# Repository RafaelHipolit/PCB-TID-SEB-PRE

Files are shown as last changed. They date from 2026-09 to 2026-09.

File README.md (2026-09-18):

# Projeto de PCB da IC: Instrumentação para o Estudo de Efeitos de Radiação em Dispositivos Eletrônicos

## Resumo da IC
O avanço da microeletrônica e a constante aplicação de dispositivos semicondutores em ambientes críticos, como os cenários aeroespaciais e nucleares, têm intensificado a necessidade de qualificar componentes eletrônicos quanto à sua tolerância à radiação ionizante. Nesse contexto, a caracterização precisa dos danos provocados exige instrumentação científica capaz de avaliar tanto os efeitos acumulativos, resultantes da Dose Ionizante Total (TID), quanto as falhas estocásticas provocadas por Efeitos de Evento Único (SEE). O presente trabalho teve como objetivo projetar e desenvolver uma plataforma eletrônica integrada, no formato de Placa de Circuito Impresso (PCB), dedicada ao estudo e à caracterização dos efeitos de radiação ionizante em transistores MOSFET de potência. 
        
O circuito implementado foi estruturado em três blocos funcionais distintos: um circuito para monitoramento de TID conectado à plataforma PXI, um circuito protetivo contra Efeitos de Queima por Sobrecorrente (SEB) baseado na Técnica de Limitação de Corrente e um circuito auxiliar de pré-amplificação focado na Espectroscopia de Carga.  Para viabilizar o uso dinâmico da plataforma sem a necessidade de reconfigurações manuais, a alternância de conexão entre os blocos operacionais e o Dispositivo Sob Teste (DUT) foi estabelecida por meio do chaveamento de relés de potência. O projeto elétrico, o layout das camadas e o modelo 3D da PCB foram desenvolvidos e validados computacionalmente no software KiCad, confirmando que a topologia concebida cumpre os requisitos de instrumentação.

---

# Metodologia

As técnicas de medição de efeitos de radiação em transistores, como a
Técnica de Limitação de Corrente e Técnica de Espectroscopia de Carga,
necessitam de componentes e equipamentos que existem comercialmente e
são comumente encontradas em laboratórios de física nuclear. Entretanto,
devido à grande variedade de dispositivos eletrônicos necessários para
implementar as diferentes técnicas, não existe uma solução comercial
viável de propósito geral para qualificação de transistores sob efeitos
de radiação. Assim, percebe-se uma necessidade de desenvolver uma
plataforma integrada de testes suficientemente geral que atenda
simultaneamente às exigências específicas de ensaios de efeitos
estocásticos e acumulativos de radiação para uma ampla gama de
transistores.

Tendo esse contexto em mente, este projeto de pesquisa visa projetar uma
plataforma integrada, na forma de placa de circuito impresso (PCB -
*Printed Circuit Board*) que auxilie o estudo e caracterização dos
efeitos de radiação ionizante em dispositivos eletrônicos. A PCB a ser
elaborada deve focar em TID para efeitos acumulativos e SEE para efeitos
estocásticos. Para medição de SEE deve-se utilizar a Técnica de
Limitação de Corrente e Técnica de Espectroscopia de Carga.

O circuito projetado na PCB deve ser dividido em três blocos: Circuito
TID, Circuito SEB e Circuito Pré-Amplificador. Os três circuitos devem
ser integrados de forma que apenas um esteja conectado ao DUT por vez e
que a troca do circuito conectado ao DUT possa ser realizada
dinamicamente.

## Circuito TID

Esse circuito deve auxiliar na medição do efeito de TID. Para isso ele
deve conectar os terminais do DUT a uma SMU para monitoramento de
parâmetros do dispositivo. No caso desse projeto, a SMU será por meio da
plataforma modular PXI (*PCI eXtensions for Instrumentation*). Portanto,
a saída deste circuito deve obedecer a padronização de conexão com a
plataforma PXI. Tal padrão consiste de nove eletrodos de controle e
automação, que obedece o seguinte ordenamento sequencial:

-   Eletrodo positivo de porta (POS G).

-   Eletrodo negativo de porta (NEG G).

-   Eletrodo positivo de dreno (POS D).

-   Eletrodo negativo de dreno (NED G).

-   Eletrodo negativo de sensoriamento de dreno (NEG SD).

-   Eletrodo positivo de sensoriamento de dreno (POS SD).

-   Fonte DC (+5 V).

-   Fonte DC (+5 V).

-   Fonte DC (+5 V).

Em nosso contexto, os últimos três terminais de fonte DC +5 V são
utilizados para controle automatizado de relês de alta tensão.

## Circuito SEB

O Circuito SEB deve auxiliar a medição do Efeito Único de Queima por
Sobrecorrente. Para isso, ele deve implementar a Técnica de Limitação de
Corrente com um arranjo de resistores de proteção. A saída do circuito
deve disponibiliza os sinais transientes do DUT para instrumentos
externos de aquisição. O terminal de saída desse circuito deve possuir
impedância de 50para evitar reflexões em sistemas de aquisição
ultra-rápidos. Além disso, o sistema protetivo deve possibilitar a
seleção do resistor de proteção apropriado (10 k- 1 M) ao DUT, de forma
a assegurar a eficácia da técnica de limitação de corrente.

## Circuito Pré-Amplificador

O Circuito Pré-Amplificador deve auxiliar o arranjo da Técnica de
Espectroscopia de Carga por meio da implementação do Pré-Amplificador
Sensível à Carga presente nesta técnica. Sua saída deve apresentar
impedância de 50 ohms para casamento com sistemas de aquisição
ultra-rápidos. Para definir o ganho nominal de pré-amplificação de
aproximadamente 45 mV/MeV em sensores de silício, um capacitor de
retroalimentação de 1 pF foi escolhido. Para possibilitar a
discriminação de eventos distintos induzidos por partículas ionizantes a
taxas médias inferiores a $2 \times 10^{6}$ eventos/s, tipicamente
adotadas em testes dedicados com aceleradores de partículas, um resistor
de retroalimentação de 100 kfoi considerado.

## Integração dos circuitos

Os três circuitos devem ser integrados de forma que apenas um esteja
conectado ao DUT por vez. Para realizar essa alternância de conexão deve
ser utilizados relés de potência para conectar apenas um dos circuitos
por vez ao DUT. O controle desses relés deve ser por meio plataforma
PXI, utilizando a conexão implementada no Circuito TID.

## Conexão com o transistor DUT

Visando o propósito generalista da plataforma integrada de testes e
buscando maior praticidade na substituição de diferentes DUTs na
instrumentação proposta, optou-se por realizar a conexão entre o DUT e o
sistema por meio do acoplamento entre uma PCB-mãe (sistema) e uma
PCB-filha (DUT), através de barras de pinos torneados. A PCB-filha deve
passar os sinais de porta, dreno e fonte. O uso dessa arquitetura
modular justifica-se por sua disponibilidade prévia no Laboratório onde
este projeto é realizado, facilitando o uso de diferentes transistores
na PCB elaborada neste projeto.

# Resultados

Este capítulo descreve o projeto de PCB elaborada para atender ao
objetivos do presente trabalho.

## Esquemático da PCB

A Figura mostra o esquemático da PCB
elaborada no software KiCad.

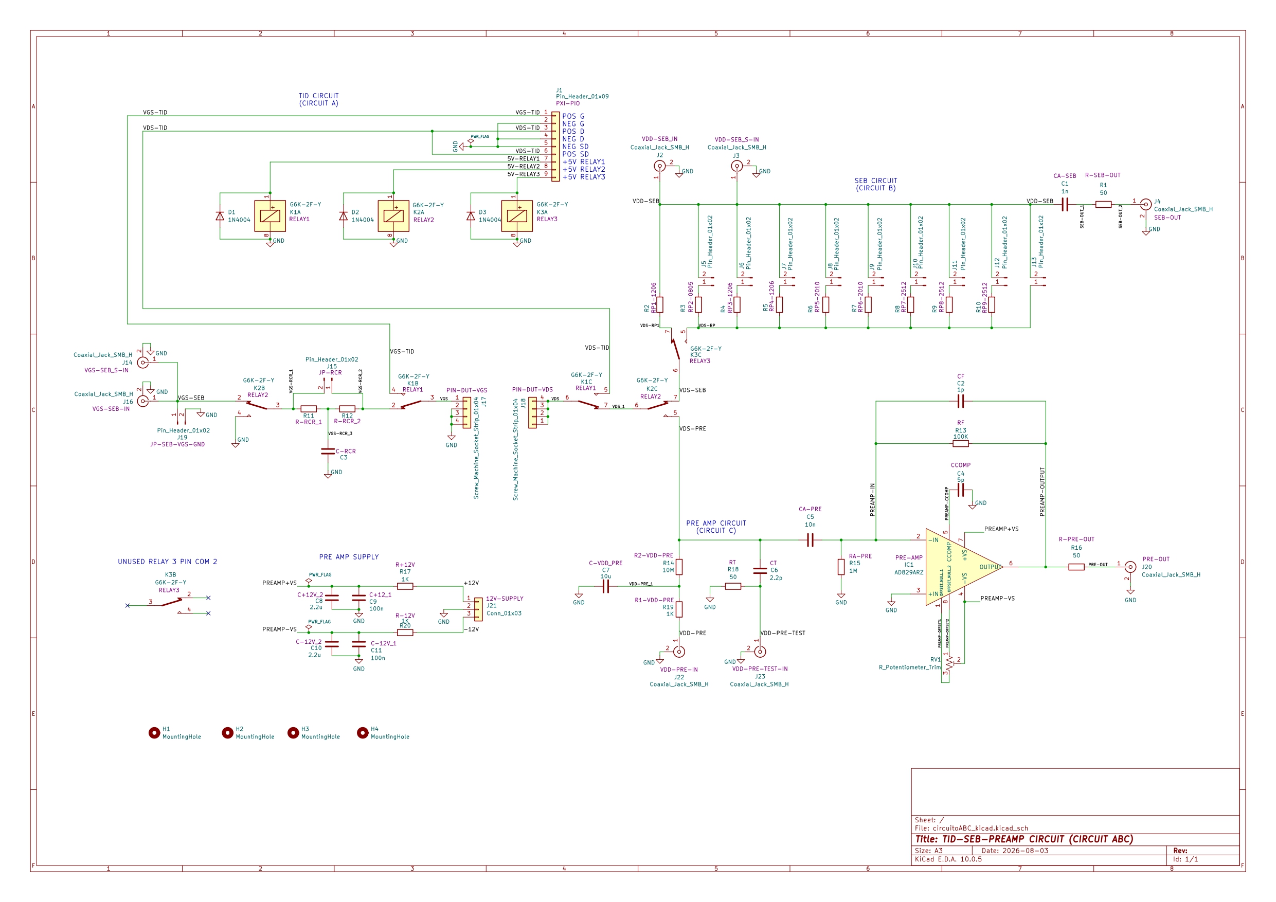
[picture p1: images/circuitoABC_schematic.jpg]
Esquemático da PCB.


Esquemático da PCB.

Esquemático da
PCB.

### Configuração da interface PXI

Os 9 pinos que se conectam à interface PXI seguem a estrutura na PCB:

-   POS G: sinal de tensão do *gate-source* do transistor.

-   NEG G: sinal de terra.

-   POS D: sinal de tensão do *drain-source* do transistor.

-   NEG D: sinal de terra.

-   NEG SD: sinal de terra.

-   POS SD: sinal de tensão do *drain-source* do transistor.

-   +5V RELAY1: ativa o relé 1 com 5V.

-   +5V RELAY2: ativa o relé 2 com 5V.

-   +5V RELAY3: ativa o relé 3 com 5V.

### Arranjo de resistores de proteção

No circuito SEB, devido a diferentes possíveis necessidades de valor
para o resistor de proteção empregado na Técnica de Limitação de
Corrente, foi elaborado um arranjo de resistores de proteção. Neste
arranjo há espaço para 9 resistores de proteção.

A conexão do resistor RP1 ou dos demais resistores pode ser alterada
dinamicamente utilizando o relé 3. Os resistores RP2 até RP9 estão
conectados em paralelo, porém cada um pode ser desconectado manualmente
utilizando um jumper. Ademais, uma trilha para conexão sem resistor de
proteção está presente.

### Configuração dos relés

Foram utilizados 3 relés duplos, ou seja, 3 circuitos integrados nos
quais cada um contém 2 relés que são ativados simultaneamente. Os relés
1 e 2 realizam a troca de conexão dos circuitos com o DUT. O relé 3
realiza a troca de resistor de proteção dinamicamente. A tabela descreve
a configuração de cada relé.

| -------- |--------------------- |---------------------------------| 
| --- |--- |---|
| Relé 1 |Normalmente Aberto |Conecta o porta e dreno do DUT ao Circuito TID| 
| |Normalmente Fechado |Conecta o porta e dreno do DUT ao Circuito SEB ou Pré-Amp.|
| -------- |--------------------- |--------------------------------|
| Relé 2 |Normalmente Aberto |Conecta o porta e dreno do DUT ao Circuito Pré-Amplificador | 
| |Normalmente Fechado |Conecta o porta e dreno do DUT ao Circuito SEB|
| -------- |--------------------- |--------------------------------|
| Relé 3 |Normalmente Aberto |Utiliza o resistores RP2 a RP9 como resistor de proteção | 
| |Normalmente Fechado |Utiliza o resistor RP1 como resistor de proteção|
| -------- |--------------------- |--------------------------------|

Configuração de cada relé.

## Layout da PCB

A Figura mostra o layout da PCB elaborada no
software KiCad. Na esquerda da PCB se encontra o Circuito SEB e Circuito
TID. Na borda da placa, encontram-se os conectores dos sinais de entrada
e saída do Circuito SEB. Em seguida é visível o arranjo de resistores de
proteção, os 3 relés e os pinos para conexão do Circuito TID com a
plataforma PXI. No centro da PCB encontram-se os pinos para conexão com
a PCB-filha e, portanto, conexão com o DUT. Na direita da PCB há o
Circuito Pré-Amplificador.

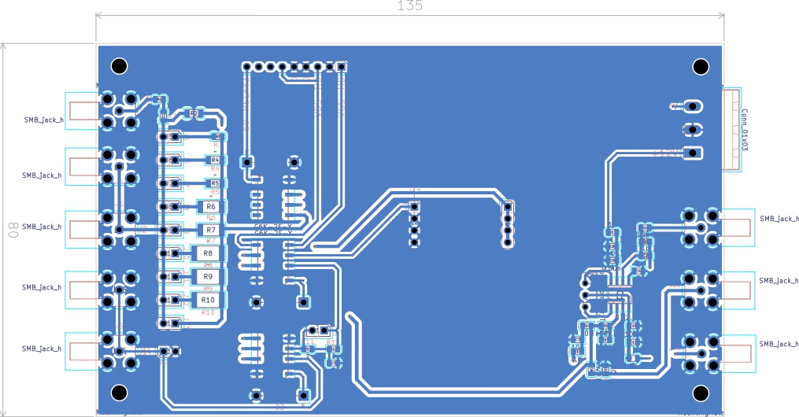
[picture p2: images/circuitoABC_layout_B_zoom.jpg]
Layout da camada inferior da PCB.


Layout da camada inferior da PCB.

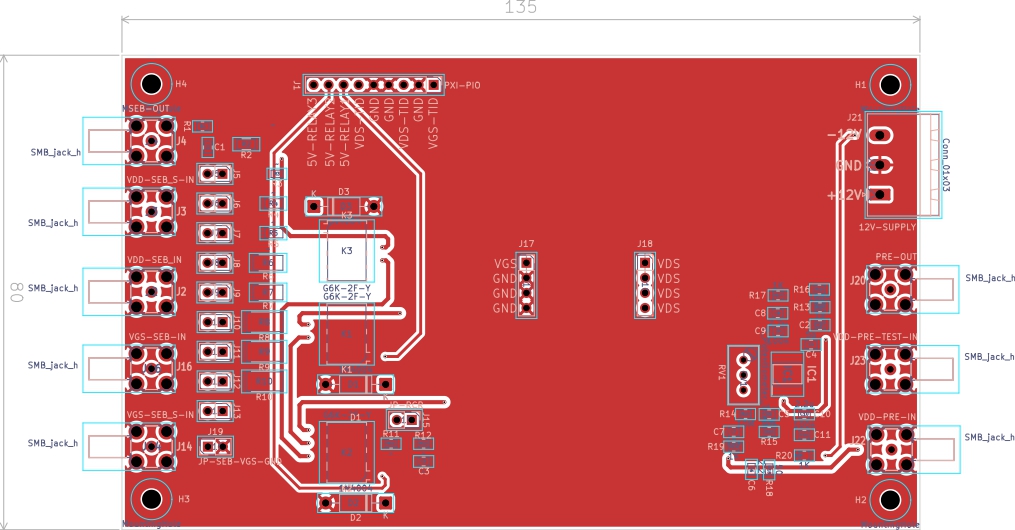
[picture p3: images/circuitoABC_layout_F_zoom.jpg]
Layout da camada superior da PCB


Layout da camada superior da PCB

A Figura mostra o modelo 3D da PCB no software
KiCad, no qual é possível visualizar todos os componentes da placa e as
legendas impressas na camada de serigrafia (*silkscreen*) dos conectores
de entrada e saída dos sinais.

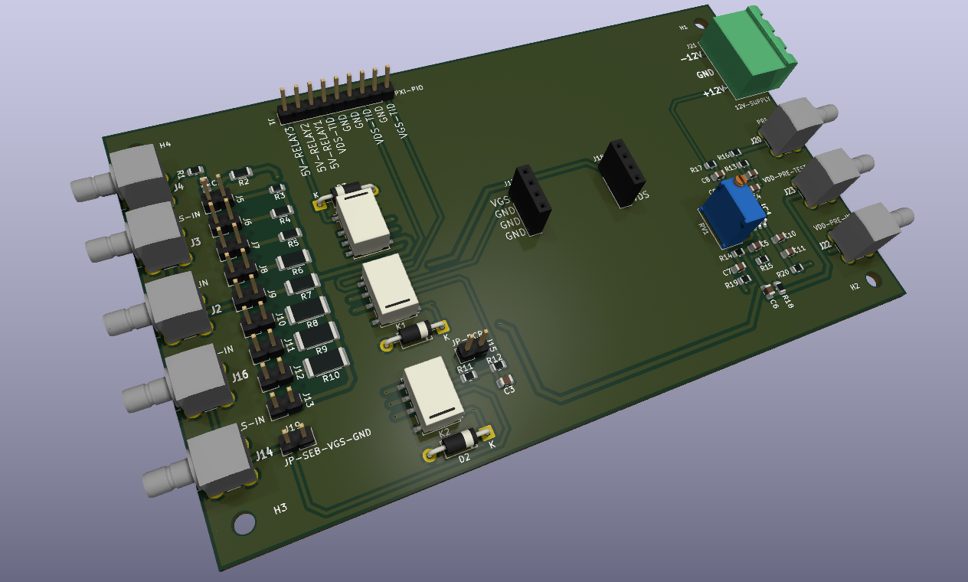
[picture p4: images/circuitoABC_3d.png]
Modelo 3D da PCB no software KiCad. Visualização da camada inferior.


Modelo 3D da PCB no software KiCad. Visualização da camada
inferior.

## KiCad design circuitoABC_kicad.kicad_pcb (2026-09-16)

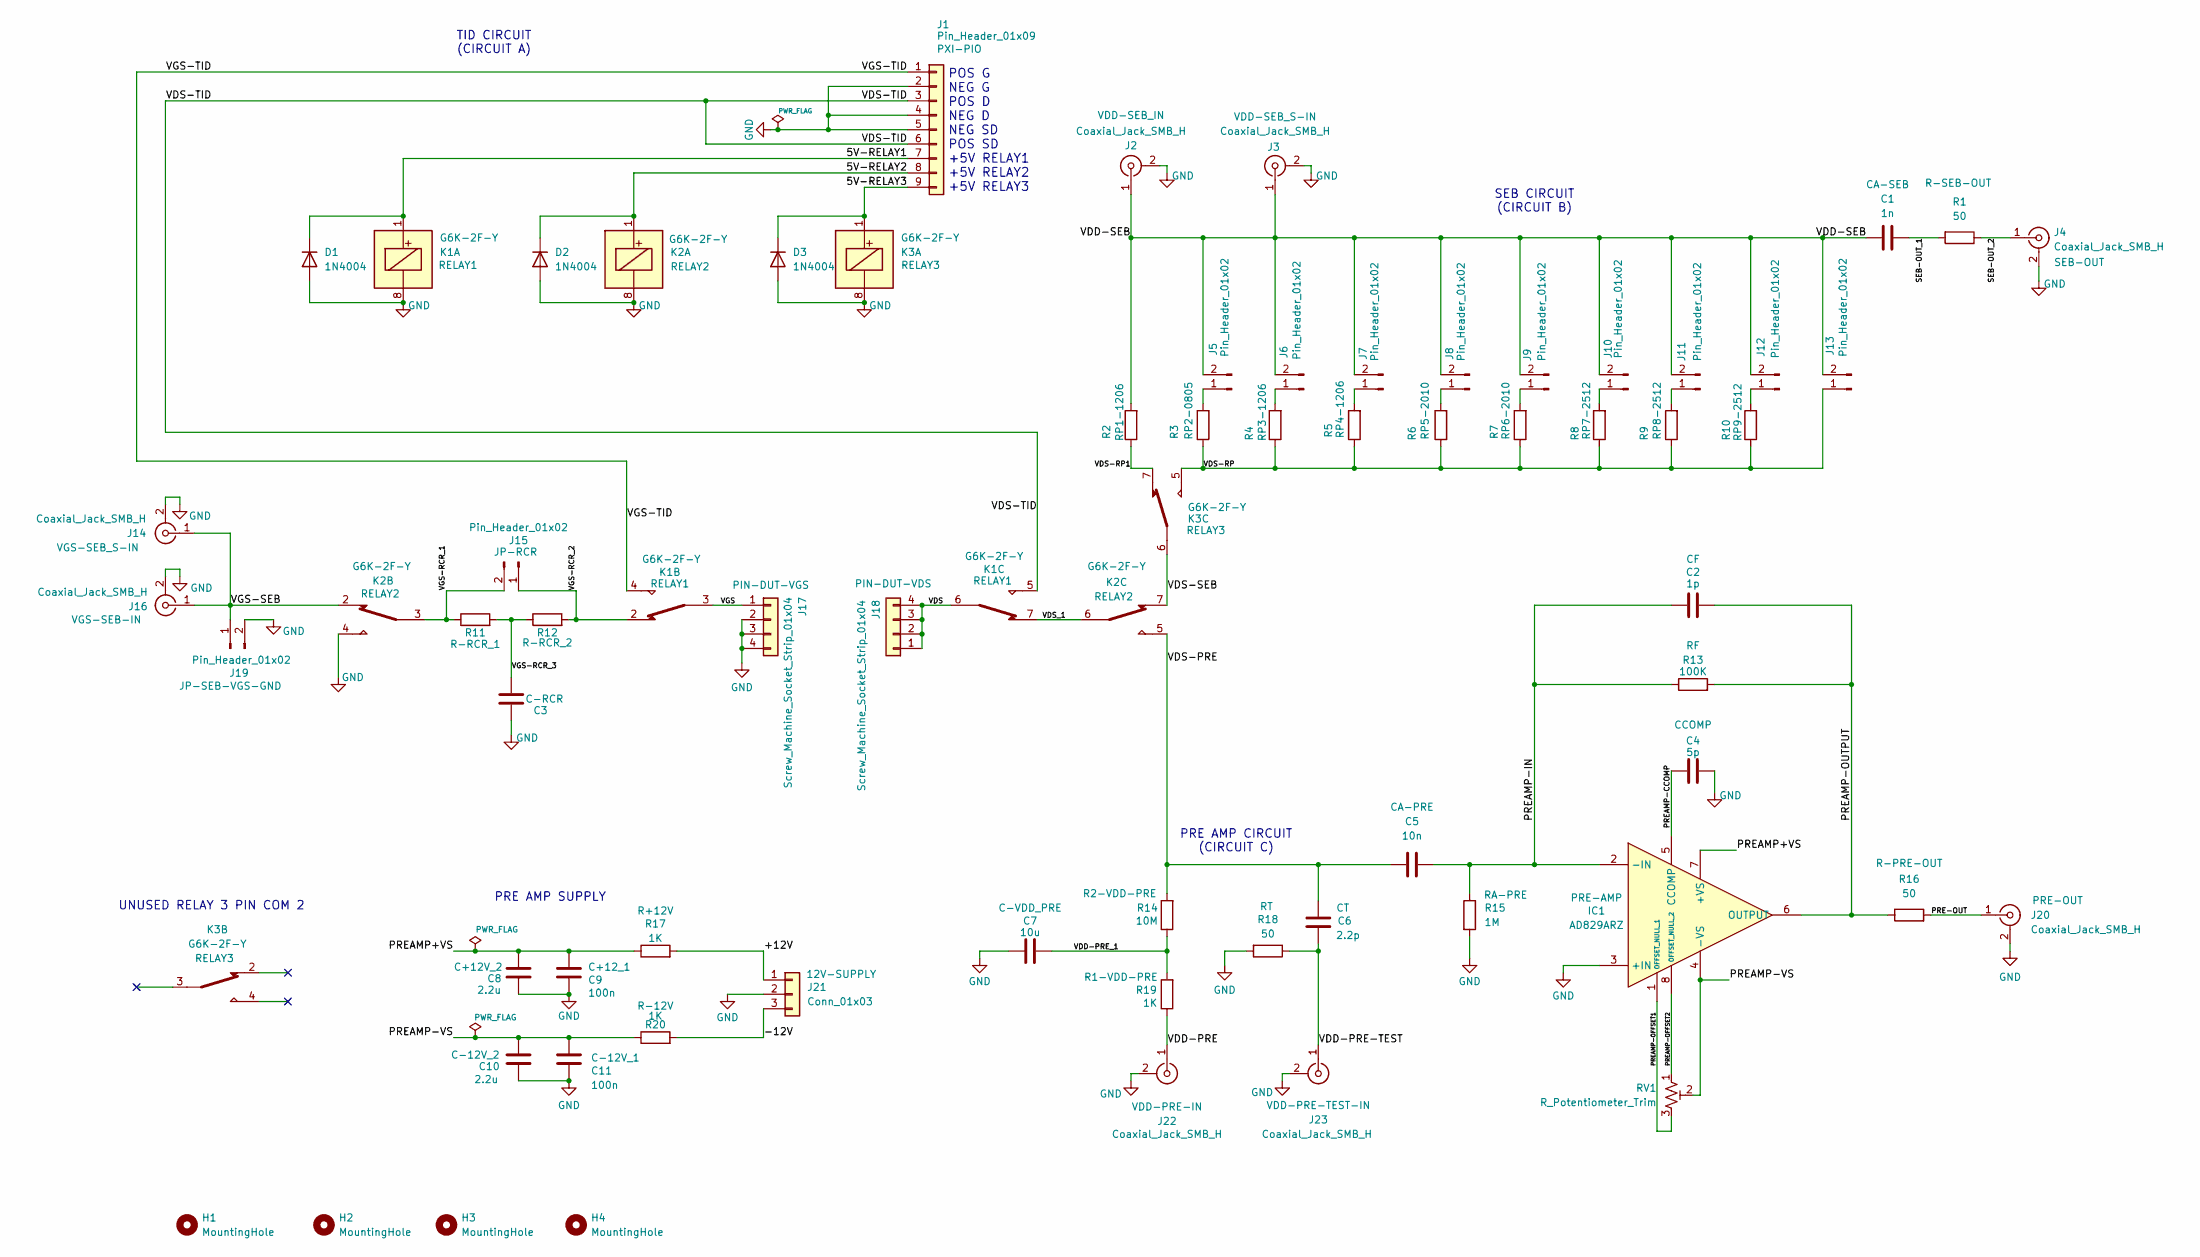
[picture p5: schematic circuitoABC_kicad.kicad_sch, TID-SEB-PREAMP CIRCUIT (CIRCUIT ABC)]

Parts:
C1: 1n; C_0805_2012Metric
C2: 1p; C_0805_2012Metric
C3: C_0805_2012Metric
C4: 5p; C_0805_2012Metric
C5: 10n; C_0805_2012Metric
C6: 2.2p; C_0805_2012Metric
C7: 10u; C_0805_2012Metric
C8, C10: 2.2u; C_0805_2012Metric
C9, C11: 100n; C_0805_2012Metric
D1, D2, D3: 1N4004; D_DO-41_SOD81_P10.16mm_Horizontal
H1, H2, H3, H4: MountingHole; MountingHole_3.2mm_M3
IC1: AD829ARZ; SOIC127P600X175-8N; Manufacturer_Part_Number AD829ARZ; Mouser Part Number 584-AD829ARZ
J1: Pin_Header_01x09; PinHeader_1x09_P2.54mm_Vertical
J2, J3, J4, J14, J16, J20, J22, J23: Coaxial_Jack_SMB_H; 731000103
J5, J6, J7, J8, J9, J10, J11, J12, J13, J15, J19: Pin_Header_01x02; PinHeader_1x02_P2.54mm_Vertical
J17, J18: Screw_Machine_Socket_Strip_01x04; PinSocket_1x04_P2.54mm_Vertical
J21: Conn_01x03; PhoenixContact_MSTBA_2,5_3-G_1x03_P5.00mm_Horizontal
K1, K2, K3: G6K-2F-Y; Relay_DPDT_Omron_G6K-2F-Y
R1, R16, R18: 50; R_0805_2012Metric
R2, R4, R5: R_1206_3216Metric
R3, R11, R12: R_0805_2012Metric
R6, R7: R_2010_5025Metric
R8, R9, R10: R_2512_6332Metric
R13: 100K; R_0805_2012Metric
R14: 10M; R_0805_2012Metric
R15: 1M; R_0805_2012Metric
R17, R19, R20: 1K; R_0805_2012Metric
RV1: R_Potentiometer_Trim; Potentiometer_Bourns_3296W_Vertical

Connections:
/5V-RELAY1: D1.1 (K), J1.7, K1.1
/5V-RELAY2: D2.1 (K), J1.8, K2.1
/5V-RELAY3: D3.1 (K), J1.9, K3.1
/+12V: J21.1, R17.2
/-12V: J21.3, R20.2
/PRE-OUT: J20.1 (In), R16.2
/PREAMP+VS: C8.2, C9.2, IC1.7 (+VS), R17.1
/PREAMP-CCOMP: C4.2, IC1.5 (CCOMP)
/PREAMP-IN: C2.1, C5.2, IC1.2 (-IN), R13.1, R15.1
/PREAMP-OFFSET1: IC1.1 (OFFSET_NULL_1), RV1.3
/PREAMP-OFFSET2: IC1.8 (OFFSET_NULL_2), RV1.1
/PREAMP-OUTPUT: C2.2, IC1.6 (OUTPUT), R13.2, R16.1
/PREAMP-VS: C10.2, C11.2, IC1.4 (-VS), R20.1, RV1.2
/SEB-OUT_1: C1.2, R1.2
/SEB-OUT_2: J4.1 (In), R1.1
/VDD-PRE: J22.1 (In), R19.1
/VDD-PRE-TEST: C6.1, J23.1 (In), R18.1
/VDD-PRE_1: C7.2, R14.1, R19.2
/VDD-SEB: C1.1, J2.1 (In), J3.1 (In), J5.2, J6.2, J7.2, J8.2, J9.2, J10.2, J11.2, J12.2, J13.2, R2.2
/VDS: J18.1, J18.2, J18.3, J18.4, K1.6
/VDS-PRE: C5.1, C6.2, K2.5, R14.2
/VDS-RP: J13.1, K3.5, R3.1, R4.1, R5.1, R6.1, R7.1, R8.1, R9.1, R10.1
/VDS-RP1: K3.7, R2.1
/VDS-SEB: K2.7, K3.6
/VDS-TID: J1.3, J1.6, K1.5
/VDS_1: K1.7, K2.6
/VGS: J17.1, K1.3
/VGS-RCR_1: J15.2, K2.3, R11.1
/VGS-RCR_2: J15.1, K1.2, R12.2
/VGS-RCR_3: C3.1, R11.2, R12.1
/VGS-SEB: J14.1 (In), J16.1 (In), J19.1, K2.2
/VGS-TID: J1.1, K1.4
GND: C3.2, C4.1, C7.1, C8.1, C9.1, C10.1, C11.1, D1.2 (A), D2.2 (A), D3.2 (A), IC1.3 (+IN), J1.2, J1.4, J1.5, J2.2 (Ext), J3.2 (Ext), J4.2 (Ext), J14.2 (Ext), J16.2 (Ext), J17.2, J17.3, J17.4, J19.2, J20.2 (Ext), J21.2, J22.2 (Ext), J23.2 (Ext), K1.8, K2.4, K2.8, K3.8, R15.2, R18.2
unnamed: J5.1, R3.2
unnamed: J6.1, R4.2
unnamed: J7.1, R5.2
unnamed: J8.1, R6.2
unnamed: J9.1, R7.2
unnamed: J10.1, R8.2
unnamed: J11.1, R9.2
unnamed: J12.1, R10.2

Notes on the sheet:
PRE AMP CIRCUIT (CIRCUIT C)
PRE AMP SUPPLY
UNUSED RELAY 3 PIN COM 2
POS G NEG G POS D NEG D NEG SD POS SD +5V RELAY1 +5V RELAY2 +5V RELAY3
TID CIRCUIT (CIRCUIT A)
SEB CIRCUIT (CIRCUIT B)

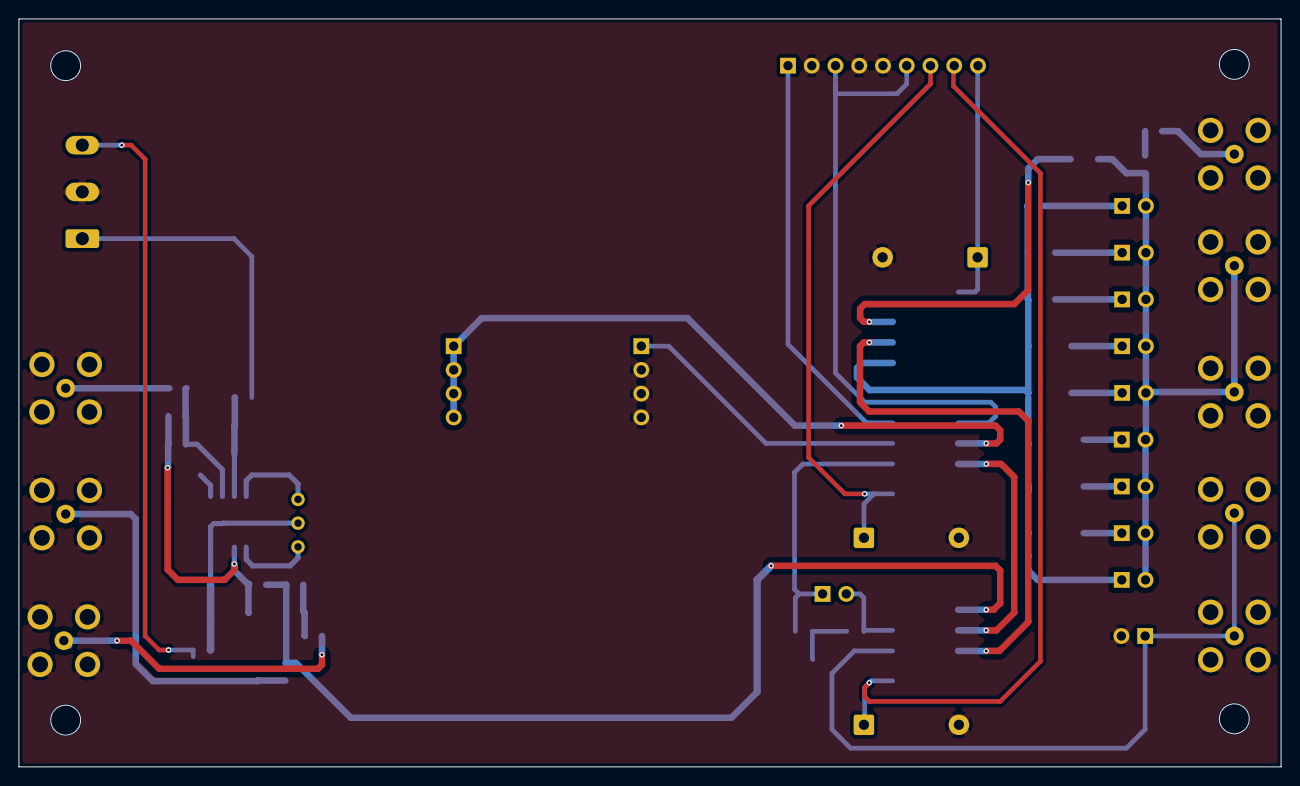
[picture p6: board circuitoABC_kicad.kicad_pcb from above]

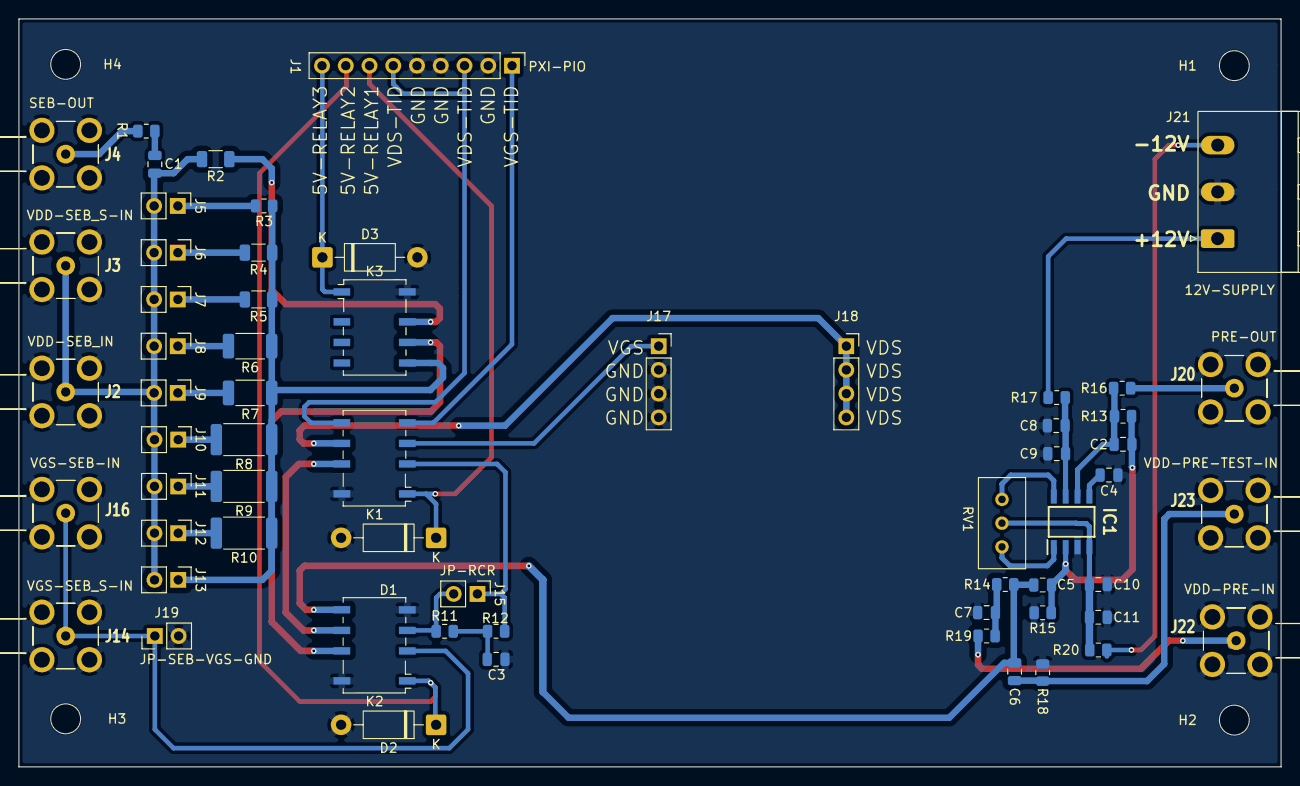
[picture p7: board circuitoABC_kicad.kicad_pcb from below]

Board: 2 copper layers, 135.0 x 80.0 mm, 66 parts (66 on the bottom side), 41 nets.

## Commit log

2026-09-11 Commit inicial do projeto KiCad
    [circuitoABC_kicad.kicad_pcb, circuitoABC_kicad.kicad_sch]
2026-09-11 Add project description for PCB design
    Added project overview and summary for PCB
2026-09-16 fix: add proj specific libs
    [circuitoABC_kicad.kicad_pcb]
2026-09-18 Enhance README with project methodology and details
    Expanded the README with detailed methodology, circuit descriptions, and PCB layout information for the radiation effects study.
2026-09-18 Change images from PDF to JPG and update table
    Updated image formats in README and modified relay configuration table.
